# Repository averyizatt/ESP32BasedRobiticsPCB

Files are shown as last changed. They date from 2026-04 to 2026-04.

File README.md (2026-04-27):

# ESP32-S3 Robotics Controller PCB

<div align="center">







**A professional-grade, 4-layer ESP32-S3 robotics controller PCB that consolidates motor control, multi-axis sensing, and user interaction into a single, scalable platform.**

</div>

---

## Table of Contents

1. [Board Gallery](#board-gallery)
2. [System Architecture](#system-architecture)
3. [Feature Overview](#feature-overview)
4. [PCB Design](#pcb-design)
   - [Layer Stackup](#layer-stackup)
   - [Signal Integrity](#signal-integrity)
   - [Key Components (BOM Summary)](#key-components-bom-summary)
5. [GPIO Pin Reference](#gpio-pin-reference)
6. [Peripheral Details](#peripheral-details)
   - [Motor Control — DRV8871](#motor-control--drv8871)
   - [Servo Outputs](#servo-outputs)
   - [Ultrasonic Sensors — HC-SR04](#ultrasonic-sensors--hc-sr04)
   - [Hall Effect Sensors](#hall-effect-sensors)
   - [IMU — I2C](#imu--i2c)
   - [SPI Display](#spi-display)
   - [Push Buttons](#push-buttons)
   - [Expansion Header](#expansion-header)
7. [Firmware](#firmware)
   - [Quick Start](#quick-start)
   - [Library Dependencies](#library-dependencies)
   - [Firmware Architecture](#firmware-architecture)
   - [PWM Configuration](#pwm-configuration)
   - [WiFi Access Point & Web Dashboard](#wifi-access-point--web-dashboard)
   - [BLE GATT Server](#ble-gatt-server)
   - [On-Device UI](#on-device-ui)
     - [Main Menu](#main-menu)
     - [Robot Modes](#robot-modes)
     - [Games](#games)
8. [Repository Structure](#repository-structure)
9. [Hardware Files](#hardware-files)
10. [Contributing](#contributing)
11. [License](#license)

---

## Board Gallery

<div align="center">

| PCB Layout (Top) | 3D Render | PCB Back |
|:---:|:---:|:---:|
| PCB Layout | PCB 3D Render | PCB Back |

</div>

---

## System Architecture

The diagram below shows how all onboard subsystems connect to the ESP32-S3:

```
                        ┌─────────────────────────────────────┐
                        │           ESP32-S3-WROOM-1           │
                        │     240 MHz Xtensa LX7 Dual-Core     │
                        │     WiFi 802.11 b/g/n  •  BT 5.0    │
                        └───┬───┬───┬───┬───┬───┬───┬───┬─────┘
                            │   │   │   │   │   │   │   │
          ┌─────────────────┘   │   │   │   │   │   │   └──────────────────┐
          │ LEDC PWM            │   │   │   │   │   │ GPIO ISR             │
          ▼                     │   │   │   │   │   ▼                      │
 ┌─────────────────┐            │   │   │   │   │  ┌────────────────┐      │
 │   DRV8871 ×2    │            │   │   │   │   │  │  Hall Sensors  │      │
 │  DC Motor Ctrl  │            │   │   │   │   │  │   ×2 inputs    │      │
 │  (PWM IN1/IN2)  │            │   │   │   │   │  └────────────────┘      │
 └────────┬────────┘            │   │   │   │   │                          │
          │ VM (motor power)    │   │   │   │   │ INPUT_PULLUP             │
          ▼                     │   │   │   │   ▼                          │
    ┌───────────┐               │   │   │   │  ┌──────────────┐            │
    │  Motor ×2 │               │   │   │   │  │  Buttons ×2  │            │
    └───────────┘               │   │   │   │  └──────────────┘            │
                      PWM 50Hz  │   │   │   │                              │
                                ▼   │   │   │ SPI                          │
                       ┌────────────┐  │   ▼                               │
                       │  Servo 1   │  │  ┌──────────────────┐             │
                       └────────────┘  │  │   SPI Display    │             │
                                       │  │  (ST7735 etc.)   │             │
                    HC-SR04 TRIG/ECHO  │  └──────────────────┘             │
                                       ▼                                   │
                           ┌────────────────────┐                          │
                           │  Ultrasonic ×4     │                          │
                           │  (distance 2–400cm)│                          │
                           └────────────────────┘                          │
                                                                           │
          ┌────────────────────────────────────────────────────────────────┘
          │ I2C 400 kHz
          ▼
 ┌──────────────────┐     ┌──────────────────────────────┐
 │  IMU Header      │     │      Power Architecture       │
 │  MPU-6050 /      │     │  VM (7–12 V) ──► DRV8871     │
 │  ICM-42688 etc.  │     │  VM ──► 3.3 V LDO ──► ESP32  │
 └──────────────────┘     │  VM ──► 5 V (servo/sensors)  │
                          └──────────────────────────────┘
```

---

## Feature Overview

| Subsystem | Component | Capability |
|---|---|---|
| **Microcontroller** | ESP32-S3-WROOM-1 | 240 MHz dual-core, WiFi, BT 5.0, 45 GPIOs |
| **Motor Drivers** | 2× DRV8871 | H-bridge, 3.6 A peak, bidirectional DC control |
| **Servo Outputs** | 1 active channel | Servo 1 on GPIO 8; GPIO 9 is used by the menu potentiometer |
| **Ultrasonic Sensors** | 4× HC-SR04 | 2–400 cm range, 15° beam angle |
| **Hall Effect Sensors** | 2× inputs | Wheel speed, pulse counting, position feedback |
| **IMU** | I2C header | MPU-6050, ICM-42688, or any I2C IMU |
| **SPI Display** | ST7735S 160×80 | TFT_eSPI driver, tabbed on-device UI |
| **Push Buttons** | 2× SMD tactile | Top = enter/select, bottom = back/stop; debounced in firmware |
| **Expansion** | GPIO header | GPIO 40, 43, 44, and shared GPIO 48 available for expansion |
| **Power** | LDO + distribution | Onboard 3.3 V regulation, motor VM bus |
| **WiFi AP** | Soft Access Point | SSID `RoboController`, live sensor dashboard |
| **Web Dashboard** | AsyncWebSocket | Tabbed UI: sensors, WiFi scan, BLE radar, drive control |
| **Remote Control** | WebSocket JSON | Browser joystick → motor drive; Servo 1 slider |
| **BLE GATT Server** | NimBLE-Arduino | Sensor notify + motor/servo write characteristics |
| **BLE Scanner** | Passive scan | Detect nearby BLE devices, shown on TFT and dashboard |

---

## PCB Design

### Layer Stackup

The board uses a **4-layer stackup** (1.6 mm total thickness) to provide dedicated power and ground planes, minimizing noise and improving signal integrity:

```
  ┌─────────────────────────────────────────────┐  ← Component side
  │  Layer 1 — F.Cu (Top)                        │  Signal routing + high-current motor traces
  ├─────────────────────────────────────────────┤
  │  Prepreg                                     │
  ├─────────────────────────────────────────────┤
  │  Layer 2 — In1.Cu                            │  Solid GND plane (unbroken)
  ├─────────────────────────────────────────────┤
  │  Core                                        │
  ├─────────────────────────────────────────────┤
  │  Layer 3 — In2.Cu                            │  VM + 3.3 V power distribution
  ├─────────────────────────────────────────────┤
  │  Prepreg                                     │
  ├─────────────────────────────────────────────┤
  │  Layer 4 — B.Cu (Bottom)                     │  Additional signals + local copper pours
  └─────────────────────────────────────────────┘  ← Solder side
```

| Layer | Role | Trace Width |
|---|---|---|
| F.Cu (Top) | Signal routing + high-current motor paths | 0.2 mm signal / 2.0 mm motor VM |
| In1.Cu | Solid GND reference plane | — |
| In2.Cu | VM + 3.3 V power distribution | 0.8 mm+ |
| B.Cu (Bottom) | Additional signals + local copper pours | 0.2 mm signal |

### Signal Integrity

> **Design decisions to ensure reliable operation in a noisy motor-drive environment:**

- **Continuous GND plane** on In1.Cu with stitching vias throughout — minimises return-path inductance for both digital signals and motor switching transients.
- **Wide copper pours** on VM traces and high-current motor paths — rated for DRV8871 peak current with thermal headroom.
- **Local decoupling capacitors** placed directly at each ESP32-S3 power pin and each DRV8871 VCC/VM pin — suppresses switching noise at the source.
- **Physical separation** between sensitive I2C/SPI/UART traces and high-current motor/PWM traces — reduces capacitive and inductive coupling.
- **Short SPI routes** between ESP32-S3 and the display connector — maintains signal integrity at SPI bus speeds.
- **Motor VM routed on power layer (In2.Cu)** — keeps motor current off the signal layers.

### Key Components (BOM Summary)

| Reference | Part | Package | Description |
|---|---|---|---|
| U1 | ESP32-S3-WROOM-1 | SMD module | Main MCU — 240 MHz, WiFi, BT 5.0 |
| U2 | DRV8871 | HSOP-8 | Motor driver — Motor 1 |
| U3 | DRV8871 | HSOP-8 | Motor driver — Motor 2 |
| U4 | 3.3 V LDO | SOT-223 | 3.3 V regulated power for MCU and logic |
| J1–J4 | HC-SR04 headers | 4-pin 2.54 mm | Ultrasonic sensor connectors |
| J5–J6 | Hall sensor headers | 3-pin 2.54 mm | Hall effect sensor connectors |
| J7–J8 | Motor terminals | 2-pin screw terminal | Motor output connections |
| J9 | Expansion header | 8-pin 2.54 mm | Breakout for unused GPIO |
| J10 | Display header | 7-pin 2.54 mm | SPI display connector |
| SW1–SW2 | Tactile switches | SMD | User input buttons used by current firmware |

> Full BOM with part numbers and quantities is available in [`hardware/bom/`](hardware/bom/).

---

## GPIO Pin Reference

| GPIO | Function | Type | Notes |
|---|---|---|---|
| 1 | Hall Sensor 1 | Digital Input | Interrupt-driven pulse counting |
| 2 | Hall Sensor 2 | Digital Input | Interrupt-driven pulse counting |
| 4 | Motor 1 PWM A | LEDC Output | 20 kHz PWM, 8-bit resolution |
| 5 | Motor 1 PWM B | LEDC Output | 20 kHz PWM, 8-bit resolution |
| 6 | Motor 2 PWM A | LEDC Output | 20 kHz PWM, 8-bit resolution |
| 7 | Motor 2 PWM B | LEDC Output | 20 kHz PWM, 8-bit resolution |
| 8 | Servo 1 | PWM Output | 50 Hz via ESP32Servo library |
| 9 | Potentiometer | ADC Input | Main menu scroll / analog control; Servo 2 disabled in firmware |
| 10 | Ultrasonic 1 TRIG | Digital Output | 10 µs trigger pulse |
| 11 | Ultrasonic 1 ECHO | Digital Input | Pulse width → distance |
| 12 | Ultrasonic 2 TRIG | Digital Output | |
| 13 | Ultrasonic 2 ECHO | Digital Input | |
| 14 | Ultrasonic 3 TRIG | Digital Output | |
| 15 | Ultrasonic 3 ECHO | Digital Input | |
| 16 | Ultrasonic 4 TRIG | Digital Output | |
| 17 | Ultrasonic 4 ECHO | Digital Input | |
| 18 | I2C SDA (IMU) | I2C | 400 kHz fast mode |
| 21 | I2C SCL (IMU) | I2C | 400 kHz fast mode |
| 35 | SPI CS | SPI | Active low chip select |
| 36 | SPI DC | Digital Output | Data/Command select |
| 37 | SPI MOSI (Display) | SPI | SDA label on display module |
| 38 | SPI SCLK (Display) | SPI | SCL label on display module |
| 39 | SPI RES | Digital Output | Display reset |
| 41 | Button 1 | Digital Input | `INPUT_PULLUP`, active LOW |
| 42 | Button 2 | Digital Input | `INPUT_PULLUP`, active LOW |
| 48 | Onboard RGB LED | Digital Output | WS2812 / NeoPixel |
| 40, 43, 44 | Expansion Header | GPIO | General purpose — broken out to J9 |

---

## Peripheral Details

### Motor Control — DRV8871

The **DRV8871** is a brushed DC motor driver with an integrated H-bridge, supporting up to **3.6 A peak** current with current-limit protection. Two independent drivers are included for dual-motor operation.

| Motor | PWM A GPIO | PWM B GPIO | LEDC Channel A | LEDC Channel B |
|---|---|---|---|---|
| Motor 1 | 4 | 5 | 0 | 1 |
| Motor 2 | 6 | 7 | 2 | 3 |

**Control truth table:**

| Mode | PWM A | PWM B | Description |
|---|---|---|---|
| Forward | PWM duty | LOW | Speed proportional to duty cycle |
| Reverse | LOW | PWM duty | Speed proportional to duty cycle |
| Coast | LOW | LOW | Motor freewheels (no braking) |
| Brake | HIGH | HIGH | Active braking, motor stops quickly |

```cpp
// Example: drive Motor 1 forward at ~70% speed
motor_set(MotorId::MOTOR1, 180);   // 180/255 ≈ 70%

// Brake Motor 1
motor_brake(MotorId::MOTOR1);

// Coast Motor 2
motor_coast(MotorId::MOTOR2);
```

> **PWM frequency:** 20 kHz (above audible range — eliminates motor whine).  
> **Resolution:** 8-bit (0–255 duty cycle values).

---

### Servo Outputs

Servo 1 outputs a standard 50 Hz RC-servo PWM signal compatible with common hobby servos. Servo 2 hardware exists on GPIO 9, but the current firmware repurposes GPIO 9 as the ADC potentiometer input, so only Servo 1 is active.

| Servo | GPIO | Pulse Width Range |
|---|---|---|
| Servo 1 | 8 | 1000–2000 µs |
| Servo 2 | 9 | Disabled in current firmware; GPIO 9 is `POT_PIN` |

**Pulse width to angle mapping:**

```
1000 µs  ──►  0°   (full left)
1500 µs  ──►  90°  (center / neutral)
2000 µs  ──►  180° (full right)
```

```cpp
// Example: center Servo 1
servo_set_angle(ServoId::SERVO1, 90);
```

---

### Ultrasonic Sensors — HC-SR04

Four **HC-SR04** interfaces provide omnidirectional environmental awareness. Each sensor uses two GPIO pins: one for triggering and one for echo timing.

| Sensor | TRIG GPIO | ECHO GPIO | Max Range | Beam Angle |
|---|---|---|---|---|
| Sensor 1 | 10 | 11 | ~400 cm | ~15° |
| Sensor 2 | 12 | 13 | ~400 cm | ~15° |
| Sensor 3 | 14 | 15 | ~400 cm | ~15° |
| Sensor 4 | 16 | 17 | ~400 cm | ~15° |

**Operating principle:**

```
MCU                    HC-SR04
 │                        │
 │── 10 µs HIGH ─────────►│  TRIG pulse sent
 │                        │── 40 kHz ultrasonic burst ──►
 │                        │                    ◄── echo return
 │◄── pulse width (ECHO) ─│  width ∝ distance
 │
 Distance (cm) = pulse_width_µs × 0.0343 / 2
```

> **Timeout:** 30 ms (~5 m) — sensors beyond range return -1.

---

### Hall Effect Sensors

Two digital Hall effect sensor inputs support wheel speed measurement, odometry, and position feedback. Sensors are read via GPIO interrupts for accurate pulse counting.

| Sensor | GPIO | Mode |
|---|---|---|
| Hall 1 | 1 | Interrupt (rising edge) |
| Hall 2 | 2 | Interrupt (rising edge) |

```cpp
// Example: read rotational speed
float pps1 = hall_get_pulses_per_second(1);   // pulses per second
float pps2 = hall_get_pulses_per_second(2);
```

To calculate RPM, divide pulses per second by the number of magnet poles on the wheel.

---

### IMU — I2C

A dedicated I2C header supports any standard I2C IMU module.

| Signal | GPIO | Frequency |
|---|---|---|
| SDA | 18 | 400 kHz (fast mode) |
| SCL | 21 | 400 kHz (fast mode) |

**Compatible IMUs (non-exhaustive):**

| Part | Axes | Interface |
|---|---|---|
| MPU-6050 | 6-axis (accel + gyro) | I2C (0x68 / 0x69) |
| ICM-42688 | 6-axis (accel + gyro) | I2C / SPI |
| BNO055 | 9-axis (+ magnetometer, fusion) | I2C (0x28 / 0x29) |
| LSM6DSO | 6-axis | I2C / SPI |

```cpp
// Example: read IMU data
ImuData imu;
if (imu_read(imu)) {
    // accel in g, gyro in °/s
    Serial.printf("ax=%.2f  ay=%.2f  az=%.2f\n",
                  imu.accel_x, imu.accel_y, imu.accel_z);
}
```

---

### SPI Display

An SPI display connector supports ST7735, ST7789, ILI9341, or any SPI display with a compatible driver.

| Signal | GPIO | Function |
|---|---|---|
| MOSI (SDA) | 37 | Data to display |
| SCLK (SCL) | 38 | SPI clock |
| CS | 35 | Chip select (active LOW) |
| DC | 36 | Data / Command select |
| RES | 39 | Hardware reset |

The firmware uses **TFT_eSPI** for hardware-accelerated graphics and text rendering on the ST7735S 160×80 display. A custom colour palette and tabbed on-device UI are implemented in `display.h/cpp` and `ui.h/cpp`.

---

### Push Buttons

The current firmware uses two tactile buttons. Firmware enables `INPUT_PULLUP`, treats `LOW` as pressed, and applies software debouncing with `BUTTON_DEBOUNCE_MS` (default 20 ms).

| Button | GPIO | UI Role |
|---|---|---|
| Top button / Button 1 | 41 | Enter, open, select, primary action |
| Bottom button / Button 2 | 42 | Back, stop, return to menu |

GPIO 47 / Button 3 is not populated or used by the current 2-button UI.

```cpp
// Example: detect button press events
buttons_update();   // call every loop iteration

if (nav_enter_just_pressed()) {
    // top button pressed
}

if (nav_back_just_pressed()) {
    // bottom button pressed
}
```

---

### Expansion Header

Several GPIO pins are broken out on **J9** for custom peripherals, additional sensors, or future expansion. Some physical header pins are shared with active firmware functions, so check `config.h` before reusing them.

| Header Pin | GPIO | Notes |
|---|---|---|
| 1 | 37 | SPI display MOSI in current firmware |
| 2 | 38 | SPI display SCLK in current firmware |
| 3 | 40 | General purpose |
| 4 | 43 | UART0 TX (also used for USB CDC) |
| 5 | 44 | UART0 RX (also used for USB CDC) |
| 6 | 48 | Onboard RGB LED / WS2812 |
| 7 | 3.3 V | Power rail |
| 8 | GND | Ground |

> GPIO 43 and 44 are the default UART0 pins and can be used for serial communication with external devices.

---

## Firmware

### Quick Start

```bash
# 1. Clone the repository
git clone https://github.com/averyizatt/ESP32BasedRobiticsPCB.git

# 2. Open in PlatformIO (recommended)
#    File → Open Folder → ESP32BasedRobiticsPCB
#    PlatformIO auto-resolves all lib_deps from platformio.ini

# 3. Build
pio run --environment esp32s3

# 4. Upload
pio run --target upload --environment esp32s3
```

1. Install **PlatformIO** (VS Code extension or CLI)
2. Open the repo root as the workspace
3. PlatformIO resolves all library dependencies automatically from `platformio.ini`
4. Select the **esp32s3** environment, build, and upload
5. After boot, connect to WiFi SSID `RoboController` (password `robot1234`) and navigate to `http://192.168.4.1`

### Library Dependencies

All dependencies are declared in `platformio.ini` and resolved automatically by PlatformIO. For manual Arduino IDE installs use the Library Manager names below.

| Library | Version | Purpose |
|---|---|---|
| `madhephaestus/ESP32Servo` | ^3.0.6 | RC servo 50 Hz PWM |
| `bodmer/TFT_eSPI` | ^2.5.43 | ST7735S SPI display driver + graphics |
| `ESP32Async/AsyncTCP` | ^3.3.2 | Async TCP foundation for web server |
| `ESP32Async/ESPAsyncWebServer` | ^3.7.4 | Async HTTP + WebSocket server |
| `h2zero/NimBLE-Arduino` | ^1.4.3 | BLE stack (GATT server + scanning) |
| `Wire` | built-in | I2C for IMU |
| `WiFi` | built-in | Soft AP + network scanning |

> **TFT_eSPI user config:** The library reads pin assignments from `User_Setup.h`. Ensure the file in your PlatformIO build includes the ST7735S settings matching `config.h` (MOSI=37, SCLK=38, CS=35, DC=36, RST=39).

### Firmware Architecture

The firmware is organized as a set of independent peripheral modules — each with its own header and source file — all coordinated from `main.cpp`:

```
ESP32RoboticsController/
├── main.cpp                         ← setup() + loop() entry point
├── config.h                         ← All pin definitions and tuning constants
│
├── motors.h / motors.cpp            ← DRV8871 LEDC-based motor control
├── servos.h / servos.cpp            ← RC servo PWM control
├── ultrasonics.h / ultrasonics.cpp  ← HC-SR04 distance measurement
├── hall_sensors.h / hall_sensors.cpp← Interrupt-based pulse counting
├── imu.h / imu.cpp                  ← I2C IMU read abstraction (MPU-6050)
├── buttons.h / buttons.cpp          ← Debounced button state machine
├── led.h / led.cpp                  ← Onboard LED control
├── pot.h / pot.cpp                  ← Potentiometer / ADC helper
│
├── display.h / display.cpp          ← TFT_eSPI display abstraction + colour palette
├── ui.h / ui.cpp                    ← On-device tabbed UI state machine
├── games.h / games.cpp              ← Mini-game / demo logic
├── autonomous_modes.h / autonomous_modes.cpp
│                                      ← Autonomous driving state machine
├── robot_modes.h / robot_modes.cpp  ← Robot mode selector + active-mode runner
│
└── wifi_server.h / wifi_server.cpp  ← WiFi soft AP, AsyncWebServer, WebSocket push,
                                        BLE GATT server, WiFi/BLE scanner helpers
```

All pin assignments and tunable parameters are centralized in `config.h` — adapting the firmware to a modified hardware revision only requires editing that single file.

### PWM Configuration

Motor PWM is generated using the ESP32-S3's **LEDC peripheral**, which provides hardware-timed PWM independent of the CPU:

| Parameter | Value | Notes |
|---|---|---|
| Frequency | 20 kHz | Above human hearing — eliminates audible motor whine |
| Resolution | 8-bit | 0–255 duty cycle values |
| Channels | 4 (0–3) | One per motor H-bridge input |

---

### WiFi Access Point & Web Dashboard

The firmware starts a **soft Access Point** on boot. Connect any browser-capable device to control and monitor the robot.

| Setting | Value |
|---|---|
| SSID | `RoboController` |
| Password | `robot1234` |
| IP Address | `192.168.4.1` |
| WebSocket | `ws://192.168.4.1/ws` |

The dashboard is a single-page app served from PROGMEM with four tabs:

| Tab | Contents |
|---|---|
| **Sensors** | Live IMU (accel + gyro axis bars), ultrasonic proximity radar, heap gauge, hall encoder counts, button tiles, uptime |
| **WiFi Scanner** | Scan nearby networks — SSID, signal strength bar, channel, security badge |
| **BLE Radar** | Scan for BLE devices — name, RSSI, MAC address |
| **Control** | Virtual joystick (touch + mouse), Servo 1 control, emergency stop, command log |

Sensor data is pushed over **WebSocket** (no polling) at a configurable interval (`WIFI_WS_PUSH_MS`, default 200 ms).

#### REST Endpoints

| Endpoint | Method | Response |
|---|---|---|
| `/` | GET | Full HTML dashboard |
| `/api/scan` | GET | JSON array of nearby WiFi networks |
| `/api/ble` | GET | JSON array of scanned BLE devices (~4 s scan) |

#### WebSocket Commands (browser → robot)

The robot accepts inbound JSON commands over the same WebSocket connection:

```json
// Drive both motors (speed: -255 to +255)
{ "t": "drive", "l": 200, "r": -150 }

// Set Servo 1 angle (angle: 0–180°)
{ "t": "servo", "id": 1, "angle": 90 }

// Emergency stop — coasts both motors
{ "t": "stop" }
```

---

### BLE GATT Server

The firmware advertises a custom BLE GATT service alongside the WiFi AP — connect from **nRF Connect**, **LightBlue**, or any GATT-capable app.

| Item | UUID | Properties | Format |
|---|---|---|---|
| Service | `AB12` | — | — |
| Sensor Notify | `AA13` | Read + Notify | Compact JSON: accel, gyro, ultrasonic |
| Motor Write | `AA14` | Write | `l:<speed>,r:<speed>` e.g. `l:200,r:-150` |
| Servo Write | `AA15` | Write | `<id>:<angle>` e.g. `1:90` |

The sensor characteristic sends a live data notification every **500 ms** when a central is connected:

```json
{"ax":0.01,"ay":-0.03,"az":9.81,"gx":0.2,"gy":-0.1,"gz":0.0,"u":[45.2,120.0,-1.0,88.4]}
```

(`u` values are ultrasonic distances in cm; `-1` = no echo / out of range)

---

### On-Device UI

A tabbed menu system runs on the 160×80 TFT display. Navigation uses two push buttons and the onboard potentiometer. An auto-idle screensaver activates after 20 seconds of inactivity.

**Navigation:**
- **Top button / GPIO 41** — enter, open, select, or primary action
- **Bottom button / GPIO 42** — back, stop active mode, or return to menu
- **Potentiometer** — main menu selection and analog controls inside demos/games

In the main menu the potentiometer maps directly across the list: pot minimum selects the first item, and pot maximum selects the last item. It does not wrap around.

#### Main Menu

| Menu Item | Screen | Description |
|---|---|---|
| Sensors | Live readout | All sensor values: ultrasonic distances, hall encoder counts, button states, uptime |
| IMU Data | Live readout | Accelerometer (X/Y/Z in g) and gyroscope (X/Y/Z in °/s) with temperature |
| Tilt Demo | Animation | Graphical liquid-level tilt visualiser driven by IMU pitch/roll |
| Motors | Live readout | Current motor speed and direction for both motor channels |
| Ultrasonic | Radar demo | Real-time 4-direction proximity radar on TFT |
| Hall Demo | Live readout | Wheel pulse counts and pulses-per-second for both encoder channels |
| Servo Demo | Manual servo control | Servo 1 starts at 90°; moving the pot commands 0–180° |
| System | Info screen | Firmware uptime, heap usage, CPU frequency, chip info |
| Games | Sub-menu | Arcade game launcher (see Games section below) |
| Robot Modes | Sub-menu | Autonomous / RC mode launcher; bottom button stops active mode |
| WiFi Info | Info screen | AP SSID, password, IP address, connected client count |
| WiFi Scan | Scanner | Nearby WiFi networks with RSSI bars; pot scrolls list |
| BLE Radar | Scanner | Nearby BLE devices with RSSI bars; 4-second active scan |

#### Robot Modes

The Robot Modes menu starts the autonomous-mode engine from the display UI. The top button starts the highlighted mode, the bottom button exits the menu, and while a mode is running the bottom button stops the mode and returns to the Robot Modes list.

| Mode | Description |
|---|---|
| RC Control | Xbox BLE joystick / tank-drive control |
| UART Control | UART-commanded forward control |
| Socket Ctrl | Socket motor pass-through |
| Autonomous | Advanced state-machine mode |
| Simple Auto | PID forward motion with recovery behavior |
| Wall Follow | Left-hand PID wall follower |
| Premap Nav | Map-seeded autonomous navigation |

#### Games

The Games menu launches a sub-menu with three sprite-rendered arcade games. All games use a **full-screen off-screen framebuffer** (TFT_eSprite) pushed via DMA for zero-flicker 40 fps rendering. Win/loss statistics are stored in RAM for the session and displayed in the game menu next to each title.

---

##### Snake

> Classic snake — eat food to grow, avoid your own tail. Walls wrap.

| Detail | Value |
|---|---|
| Grid | 40 × 14 cells (4 px each) |
| Win condition | Score 20 food pieces |
| Controls | Potentiometer zones or top button to turn; bottom returns from game-over/menu screens |
| Speed | Increases with score (160 ms → 50 ms minimum tick) |
| Visual effects | Gradient tail fade, pulsing food, particle burst on eat/death, screen shake on collision |

---

##### Pong

> Single-player Pong — keep the ball alive and score paddle hits.

| Detail | Value |
|---|---|
| Win condition | 10 paddle hits |
| Lives | 3 |
| Controls | Potentiometer maps directly to paddle Y position; top button retries from game-over |
| Difficulty | Ball speed +0.15 per hit, capped at 5.5 px/frame |
| Visual effects | 6-frame ball trail, glowing neon paddle, particle bursts on wall/paddle hits, screen shake on miss |

---

##### Asteroids

> Side-scrolling asteroid dodge — survive as long as possible.

| Detail | Value |
|---|---|
| Win condition | Survive 1500 score ticks (~37 s at 40 fps) |
| Lives | 3 |
| Controls | Potentiometer steers ship Y (smoothed); top button retries from game-over |
| Difficulty | Rock speed 2.2 → 5.0 px/frame; spawn interval 1100 → 350 ms |
| Visual effects | 3-layer parallax starfield, procedural 8-vertex asteroid shapes, thruster flame + exhaust particles, invulnerability blink after hit, screen shake on collision |

---

All three games share:
- **Particle system** — 24-particle pool with gravity and colour fade, reused across all effects
- **Screen shake** — configurable intensity applied as DMA push offset
- **Session W/L stats** — shown in the games menu and on the game-over screen
- **LED feedback** — green on score/win, red on death/hit, blue on game start

---

## Repository Structure

```
ESP32BasedRobiticsPCB/
│
├── platformio.ini                     ← PlatformIO project config + lib_deps
│
├── firmware/
│   └── ESP32RoboticsController/
│       ├── main.cpp                   ← setup() + loop() entry point
│       ├── config.h                   ← Pin map & constants (start here)
│       ├── motors.h / motors.cpp      ← DRV8871 LEDC motor control
│       ├── servos.h / servos.cpp      ← RC servo PWM
│       ├── ultrasonics.h / ultrasonics.cpp  ← HC-SR04 distance
│       ├── hall_sensors.h / hall_sensors.cpp← Interrupt pulse counting
│       ├── imu.h / imu.cpp            ← MPU-6050 I2C abstraction
│       ├── buttons.h / buttons.cpp    ← Debounced buttons
│       ├── led.h / led.cpp            ← Onboard LED
│       ├── pot.h / pot.cpp            ← ADC potentiometer
│       ├── display.h / display.cpp    ← TFT_eSPI wrapper + colour palette
│       ├── ui.h / ui.cpp              ← On-device tabbed UI state machine
│       ├── games.h / games.cpp        ← Demo / mini-game logic
│       ├── autonomous_modes.h / autonomous_modes.cpp
│       │                                ← Autonomous driving state machine
│       ├── robot_modes.h / robot_modes.cpp
│       │                                ← Robot mode selector + active-mode runner
│       └── wifi_server.h / wifi_server.cpp  ← WiFi AP, web dashboard,
│                                              WebSocket, BLE GATT
│
└── hardware/                          # KiCad 7 PCB design files
    ├── kicadProject/
    │   ├── Tank.kicad_pro
    │   ├── Tank.kicad_sch
    │   ├── Tank.kicad_pcb
    │   └── Tank.step
    ├── gerbers/                        ← Fabrication-ready Gerber files
    └── bom/                            ← Bill of materials (bom.csv)
```

---

## Hardware Files

KiCad design files are in the [`hardware/`](hardware/) directory.

1. Install [KiCad 7](https://www.kicad.org/download/) or later
2. Open `hardware/kicadProject/Tank.kicad_pro`
3. The schematic opens in **Eeschema**; the PCB layout opens in **Pcbnew**

**Generating Gerbers for fabrication** (Pcbnew → File → Fabrication Outputs → Gerbers):

| File | Layer |
|---|---|
| `*-F_Cu.gbr` | Top copper |
| `*-In1_Cu.gbr` | Inner GND plane |
| `*-In2_Cu.gbr` | Inner power plane |
| `*-B_Cu.gbr` | Bottom copper |
| `*-F_SilkS.gbr` / `*-B_SilkS.gbr` | Silkscreen |
| `*-F_Mask.gbr` / `*-B_Mask.gbr` | Solder mask |
| `*-F_Paste.gbr` | Solder paste |
| `*-Edge_Cuts.gbr` | Board outline |
| `*.drl` | Drill file (Excellon) |

Pre-generated Gerber files are available in [`hardware/gerbers/`](hardware/gerbers/).

---

## Contributing

Contributions are welcome! To contribute:

1. Fork the repository
2. Create a feature branch (`git checkout -b feature/my-improvement`)
3. Commit your changes with a clear message
4. Open a pull request describing what you changed and why

**For hardware changes:** please include updated Gerber files and a brief description of the PCB modification.  
**For firmware changes:** please test on hardware before submitting.

---

## License

MIT License — see [LICENSE](LICENSE) for details.

---

<div align="center">

Made with ❤️ for the robotics community

</div>

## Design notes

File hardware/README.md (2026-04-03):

# Hardware — KiCad PCB Design Files

This directory contains the KiCad 7 project for the ESP32-S3 Robotics Controller PCB.

## Files

| File | Description |
|---|---|
| `ESP32RoboticsController.kicad_pro` | KiCad project file |
| `ESP32RoboticsController.kicad_sch` | Schematic |
| `ESP32RoboticsController.kicad_pcb` | PCB layout |
| `ESP32RoboticsController.kicad_dru` | Design rules |
| `fp-lib-table` | Footprint library table |
| `sym-lib-table` | Symbol library table |
| `gerbers/` | Fabrication-ready Gerber files |
| `bom/` | Bill of materials |
| `datasheets/` | Component datasheets |

## PCB Stackup

| Layer | Role |
|---|---|
| F.Cu (Top) | Signal routing + high-current paths |
| In1.Cu | Solid GND plane |
| In2.Cu | VM + regulated power distribution |
| B.Cu (Bottom) | Additional signals + local pours |

## Key Components

| Reference | Part | Package |
|---|---|---|
| U1 | ESP32-S3-WROOM-1 | SMD module |
| U2 | DRV8871 (Motor 1) | HSOP-8 |
| U3 | DRV8871 (Motor 2) | HSOP-8 |
| U4 | 3.3 V LDO regulator | SOT-223 |
| J1–J4 | Ultrasonic sensor headers | 4-pin 2.54 mm |
| J5–J6 | Hall sensor headers | 3-pin 2.54 mm |
| J7–J8 | Motor terminals | 2-pin screw terminal |
| J9 | Expansion GPIO header | 8-pin 2.54 mm |
| J10 | SPI display header | 7-pin 2.54 mm |
| SW1–SW3 | Push buttons | SMD tactile |
| DSP1 | SPI display (e.g., ST7735) | connector |

## Opening the Project

1. Install [KiCad 7](https://www.kicad.org/download/)
2. Open `ESP32RoboticsController.kicad_pro`
3. The schematic opens in Eeschema; the PCB opens in Pcbnew

## Generating Gerbers

In Pcbnew: **File → Fabrication Outputs → Gerbers**

Recommended layers for 4-layer fabrication:
- F.Cu, In1.Cu, In2.Cu, B.Cu
- F.SilkS, B.SilkS
- F.Mask, B.Mask
- Edge.Cuts
- F.Paste

## Design Rules

- Min trace width: 0.2 mm (signal), 0.8 mm (power), 2.0 mm (motor VM)
- Min via drill: 0.3 mm
- Min clearance: 0.2 mm
- Board thickness: 1.6 mm

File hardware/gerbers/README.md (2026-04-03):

# Gerber Files

Place fabrication-ready Gerber files in this directory after generating them from KiCad.

## Required Files for 4-Layer PCB Fabrication

| File | Layer |
|---|---|
| `ESP32RoboticsController-F_Cu.gbr` | Top copper |
| `ESP32RoboticsController-In1_Cu.gbr` | Inner layer 1 (GND plane) |
| `ESP32RoboticsController-In2_Cu.gbr` | Inner layer 2 (Power) |
| `ESP32RoboticsController-B_Cu.gbr` | Bottom copper |
| `ESP32RoboticsController-F_SilkS.gbr` | Front silkscreen |
| `ESP32RoboticsController-B_SilkS.gbr` | Back silkscreen |
| `ESP32RoboticsController-F_Mask.gbr` | Front solder mask |
| `ESP32RoboticsController-B_Mask.gbr` | Back solder mask |
| `ESP32RoboticsController-F_Paste.gbr` | Front solder paste |
| `ESP32RoboticsController-Edge_Cuts.gbr` | Board outline |
| `ESP32RoboticsController.drl` | Drill file (excellon) |

## Generating from KiCad 7

1. Open PCB in Pcbnew
2. File → Fabrication Outputs → Gerbers
3. Select output directory: `hardware/gerbers/`
4. Enable all required layers above
5. Click "Plot", then "Generate Drill Files"

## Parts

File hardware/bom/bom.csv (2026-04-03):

Reference | Qty | Value | Footprint | Description
U1 | 1 | ESP32-S3-WROOM-1 | RF_Module:ESP32-S3-WROOM-1 | ESP32-S3 WiFi+BT module
U2 | 1 | DRV8871 | Package_SO:HSOP-8_3.9x4.9mm_P1.27mm | H-bridge motor driver (Motor 1)
U3 | 1 | DRV8871 | Package_SO:HSOP-8_3.9x4.9mm_P1.27mm | H-bridge motor driver (Motor 2)
U4 | 1 | AMS1117-3.3 | Package_TO_SOT_SMD:SOT-223-3_TabPin2 | 3.3V 1A LDO regulator
C1 | 1 | 100uF | CP_EIA-3528-12_AVX-H | Bulk decoupling — input power
C2 | 1 | 10uF | C_0805_2012Metric | Bulk decoupling — 3.3V rail
C3-C10 | 8 | 100nF | C_0402_1005Metric | Decoupling — ESP32-S3 VDD pins
C11-C12 | 2 | 10uF | C_0805_2012Metric | Decoupling — DRV8871 VM
C13-C14 | 2 | 100nF | C_0402_1005Metric | Decoupling — DRV8871 VCC
C15-C16 | 2 | 100nF | C_0402_1005Metric | Decoupling — DRV8871 VM HF
R1-R2 | 2 | 10k | R_0402_1005Metric | I2C SDA/SCL pull-up
R3-R5 | 3 | 10k | R_0402_1005Metric | Button pull-up (if not using internal)
J1-J4 | 4 | Conn_01x04 | Connector_PinHeader_2.54mm:PinHeader_1x04_P2.54mm_Vertical | Ultrasonic sensor header (VCC GND TRIG ECHO)
J5-J6 | 2 | Conn_01x03 | Connector_PinHeader_2.54mm:PinHeader_1x03_P2.54mm_Vertical | Hall sensor header (VCC GND SIG)
J7-J8 | 2 | Conn_01x02 | Connector_Screw_PitchMetric:ScrewTerminal_1x02_P5.0mm | Motor terminal
J9 | 1 | Conn_01x08 | Connector_PinHeader_2.54mm:PinHeader_1x08_P2.54mm_Vertical | Expansion GPIO header
J10 | 1 | Conn_01x07 | Connector_PinHeader_2.54mm:PinHeader_1x07_P2.54mm_Vertical | SPI display header
J11 | 1 | Conn_01x02 | Connector_Screw_PitchMetric:ScrewTerminal_1x02_P5.0mm | Power input (VM)
J12 | 1 | Conn_01x04 | Connector_PinHeader_2.54mm:PinHeader_1x04_P2.54mm_Vertical | I2C IMU header
SW1-SW3 | 3 | SW_Push | Button_SMD:SW_SPST_TL3342 | Tactile push button

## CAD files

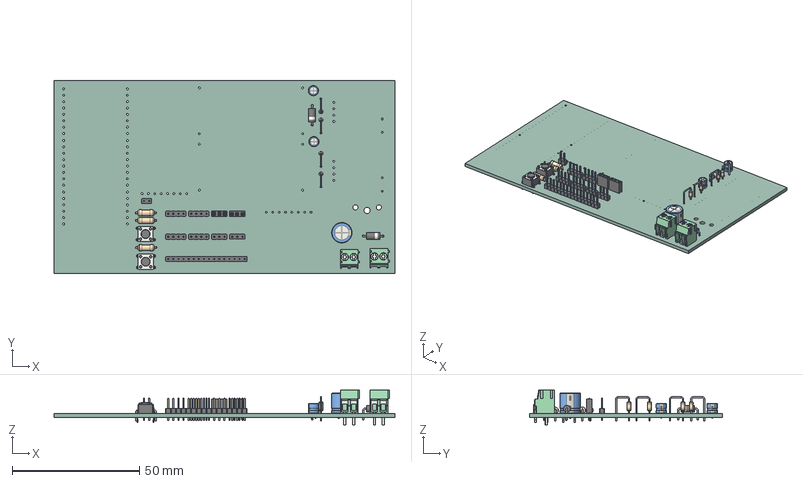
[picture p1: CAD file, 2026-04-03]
hardware/kicadProject/Tank.step
133.8 x 75.6 x 13.7 mm
PinHeader_1x04_P200mm_Vertical x 4
R_Axial_DIN0204_L36mm_D16mm_P508mm_Vertical x 4
CP_Radial_D80mm_P250mm
PinSocket_1x03_P200mm_Vertical x 2
SW_PUSH_6mm x 2
CP_Radial_D40mm_P150mm x 2
R_Axial_DIN0207_L63mm_D25mm_P762mm_Horizontal x 3
PinHeader_1x03_P200mm_Vertical x 2
TerminalBlock_Phoenix_PT_15_2_35_H_1x02_P350mm_Horizontal x 2
D_A-405_P7.62mm_Horizontal x 2
PinHeader_1x16_P200mm_Vertical
PinHeader_1x02_P200mm_Vertical
_autosave-Tank_PCB

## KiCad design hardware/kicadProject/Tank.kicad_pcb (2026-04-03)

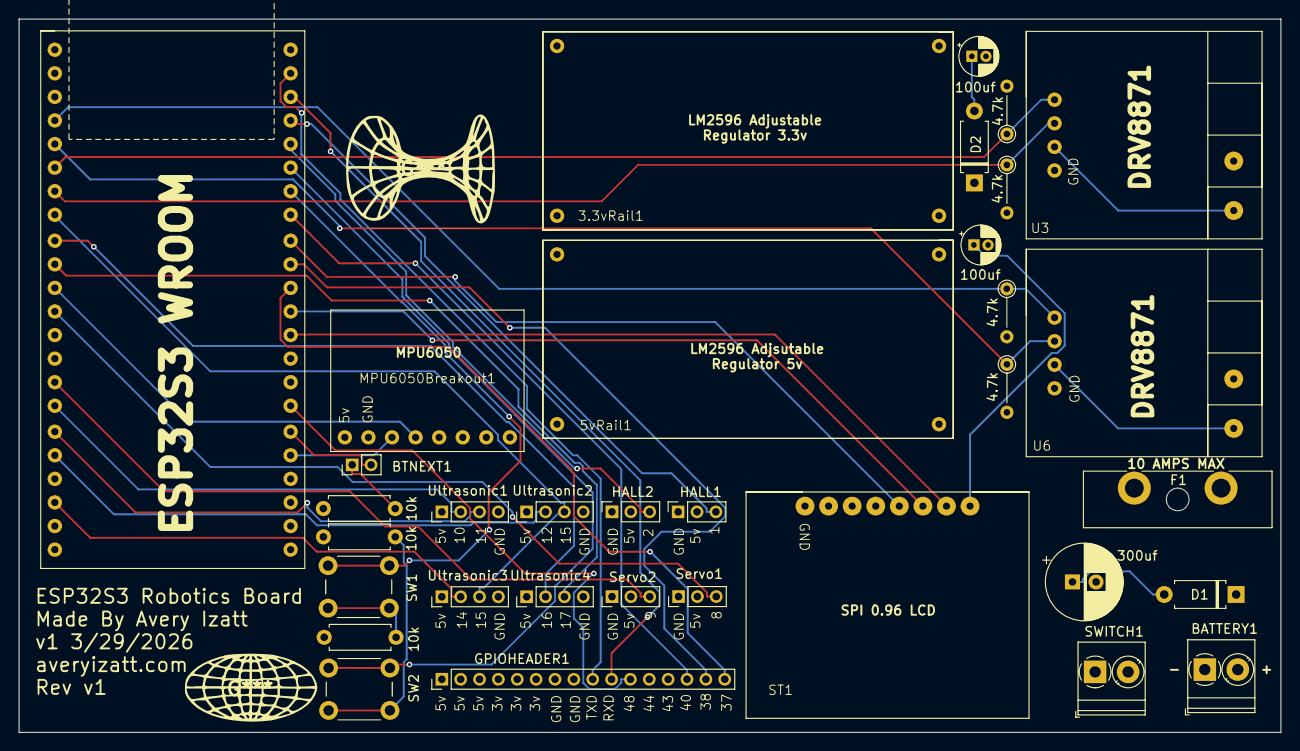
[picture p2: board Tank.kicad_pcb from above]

Board: 4 copper layers, 133.8 x 75.6 mm, 34 parts (0 on the bottom side), 40 nets.

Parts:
3.3vRail1, 5vRail1: LM2596Adj
4.7k, 4.7k#2, 4.7k#3, 4.7k#4: R; R_Axial_DIN0204_L3.6mm_D1.6mm_P5.08mm_Vertical
10k, 10k#2, 10k#3: R; R_Axial_DIN0207_L6.3mm_D2.5mm_P7.62mm_Horizontal
100uf, 100uf#2: C_Polarized; CP_Radial_D4.0mm_P1.50mm
300uf: C_Polarized; CP_Radial_D8.0mm_P2.50mm
BATTERY1: Screw_Terminal_2_P3.50mm; TerminalBlock_Phoenix_PT-1,5-2-3.5-H_1x02_P3.50mm_Horizontal
BTNEXT1: Conn_01x02_Pin; PinHeader_1x02_P2.00mm_Vertical
D1, D2: D; D_A-405_P7.62mm_Horizontal
ESP32-S3WROOM45Pin1: ESP32S3
F1: Fuse; Fuseholder_Blade_ATO_Littelfuse_Pudenz_2_Pin
GPIOHEADER1: Conn_01x16_Pin; PinHeader_1x16_P2.00mm_Vertical
HALL1, HALL2: Conn_01x03_Pin; PinSocket_1x03_P2.00mm_Vertical
MPU6050Breakout1: MPU6050
ST1: SPI 0.96 LCD
SW1, SW2: Push_Button; SW_PUSH_6mm
SWITCH1: Screw_Terminal_2_P3.50mm; TerminalBlock_Phoenix_PT-1,5-2-3.5-H_1x02_P3.50mm_Horizontal
Servo1, Servo2: Conn_01x03_Pin; PinHeader_1x03_P2.00mm_Vertical
U3, U6: DRV8871
Ultrasonic1, Ultrasonic2, Ultrasonic3, Ultrasonic4: Conn_01x04_Pin; PinHeader_1x04_P2.00mm_Vertical

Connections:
3.3V: 3.3vRail1.3 (OUT+), 100uf.1, ESP32-S3WROOM45Pin1.1 (3.3v), ESP32-S3WROOM45Pin1.2 (3.3v), GPIOHEADER1.4, GPIOHEADER1.5, GPIOHEADER1.6, ST1.2 (VCC), ST1.8 (BLK)
5V: 5vRail1.3 (OUT+), 100uf#2.1, D2.2 (A), GPIOHEADER1.1, GPIOHEADER1.2, GPIOHEADER1.3, HALL1.2, HALL2.2, MPU6050Breakout1.1 (VCC), Servo1.2, Servo2.2, Ultrasonic1.1, Ultrasonic2.1, Ultrasonic3.1, Ultrasonic4.1
GND: 3.3vRail1.2 (IN-), 3.3vRail1.4 (OUT-), 4.7k.2, 4.7k#2.2, 4.7k#3.2, 4.7k#4.2, 5vRail1.2 (IN-), 5vRail1.4 (OUT-), 10k.2, 10k#2.2, 10k#3.2, 100uf.2, 100uf#2.2, 300uf.2, BATTERY1.1, ESP32-S3WROOM45Pin1.22 (GND), ESP32-S3WROOM45Pin1.23 (GND), ESP32-S3WROOM45Pin1.43 (GND), ESP32-S3WROOM45Pin1.44 (GND), GPIOHEADER1.7, GPIOHEADER1.8, HALL1.1, HALL2.1, MPU6050Breakout1.2 (GND), ST1.1 (GND), Servo1.1, Servo2.1, U3.2 (GND), U3.6 (GND), U6.2 (GND), U6.6 (GND), Ultrasonic1.4, Ultrasonic2.4, Ultrasonic3.4, Ultrasonic4.4
GPIO1: ESP32-S3WROOM45Pin1.26 (GPIO1), HALL1.3
GPIO2: ESP32-S3WROOM45Pin1.27 (GPIO2), HALL2.3
GPIO4: 4.7k#4.1, ESP32-S3WROOM45Pin1.4 (GPIO4), U6.3 (IN1)
GPIO5: 4.7k#2.1, ESP32-S3WROOM45Pin1.5 (GPIO5), U6.4 (IN2)
GPIO6: 4.7k.1, ESP32-S3WROOM45Pin1.6 (GPIO6), U3.3 (IN1)
GPIO7: 4.7k#3.1, ESP32-S3WROOM45Pin1.7 (GPIO7), U3.4 (IN2)
GPIO8: ESP32-S3WROOM45Pin1.12 (GPIO8), Servo1.3
GPIO9: ESP32-S3WROOM45Pin1.15 (GPIO9), Servo2.3
GPIO10: ESP32-S3WROOM45Pin1.16 (GPIO10), Ultrasonic1.2
GPIO11: ESP32-S3WROOM45Pin1.17 (GPIO11), Ultrasonic1.3
GPIO12: ESP32-S3WROOM45Pin1.18 (GPIO12), Ultrasonic2.2
GPIO14: ESP32-S3WROOM45Pin1.20 (GPIO14), Ultrasonic3.2
GPIO15: ESP32-S3WROOM45Pin1.8 (GPIO15), Ultrasonic2.3, Ultrasonic3.3
GPIO16: ESP32-S3WROOM45Pin1.9 (GPIO16), Ultrasonic4.2
GPIO17: ESP32-S3WROOM45Pin1.10 (GPIO17), Ultrasonic4.3
GPIO18: ESP32-S3WROOM45Pin1.11 (GPIO18), MPU6050Breakout1.4 (SDA)
GPIO21: ESP32-S3WROOM45Pin1.40 (GPIO21), MPU6050Breakout1.3 (SCL)
GPIO35: ESP32-S3WROOM45Pin1.35 (GPIO35), ST1.7 (CS)
GPIO36: ESP32-S3WROOM45Pin1.34 (GPIO36), ST1.6 (DC)
GPIO37: ESP32-S3WROOM45Pin1.33 (GPIO37), GPIOHEADER1.16
GPIO38: ESP32-S3WROOM45Pin1.32 (GPIO38), GPIOHEADER1.15
GPIO39: ESP32-S3WROOM45Pin1.31 (GPIO39), ST1.5 (RES)
GPIO40: ESP32-S3WROOM45Pin1.30 (GPIO40), GPIOHEADER1.14
GPIO41: ESP32-S3WROOM45Pin1.29 (GPIO41), SW1.1
GPIO42: ESP32-S3WROOM45Pin1.28 (GPIO42), SW2.1
GPIO47: BTNEXT1.2, ESP32-S3WROOM45Pin1.39 (GPIO47)
GPIO48: ESP32-S3WROOM45Pin1.38 (GPIO48), GPIOHEADER1.11
unnamed: 3.3vRail1.1 (IN+), D2.1 (K)
unnamed: BATTERY1.2, F1.1
unnamed: 10k.1, BTNEXT1.1
unnamed: 300uf.1, D1.2 (A), SWITCH1.2
unnamed: F1.2, SWITCH1.1
unnamed: 10k#2.1, SW1.2
unnamed: 10k#3.1, SW2.2
RXD: ESP32-S3WROOM45Pin1.25 (RXD), GPIOHEADER1.10
TXD: ESP32-S3WROOM45Pin1.24 (TXD), GPIOHEADER1.9
VM: 5vRail1.1 (IN+), D1.1 (K), U3.1 (VM), U3.5 (VM), U6.1 (VM), U6.5 (VM)

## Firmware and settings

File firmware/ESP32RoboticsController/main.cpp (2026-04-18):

// =============================================================================
// ESP32-S3 Robotics Controller — Main Entry Point
// =============================================================================

#include <Arduino.h>
#include "config.h"
#include "display.h"
#include "buttons.h"
#include "motors.h"
#include "servos.h"
#include "ultrasonics.h"
#include "hall_sensors.h"
#include "imu.h"
#include "led.h"
#include "pot.h"
#include "wifi_server.h"
#include "ui.h"

void setup() {
    Serial.begin(115200);
    delay(200);
    Serial.println("\n[main] ESP32-S3 Robotics Controller");

    led_init();
    led_blue();

    Serial.println("[main] Initializing IMU on I2C...");
    bool imu_found = imu_init();
    Serial.printf("[main] IMU %s\n", imu_found ? "found" : "not found");

    // Display now uses its own SPI pins, so the IMU stays available on I2C.
    display_init();
    pot_init();

    wifi_server_init();

    // Boot sequence — shows splash, self-test, menu
    ui_boot(imu_found);
}

void loop() {
    buttons_update();
    pot_update();
    ui_update();
    wifi_server_update();
}

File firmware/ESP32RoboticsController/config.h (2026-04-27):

#pragma once

// =============================================================================
// ESP32-S3 Robotics Controller — Pin Configuration
// =============================================================================
// Board: ESP32S3 Dev Module
// Required libraries:
//   - ESP32Servo       (servo control)
//   - Wire             (I2C — built-in)
//   - SPI              (SPI — built-in)
//   - TFT_eSPI         (display driver, replaces Adafruit_ST7735)
//   - NimBLE-Arduino   (BLE GATT + scanner)
//   - ESPAsyncWebServer + AsyncTCP  (web dashboard)
// =============================================================================

// --- Motor 1 (DRV8871) ---
#define MOTOR1_PWM_A  4
#define MOTOR1_PWM_B  5

// --- Motor 2 (DRV8871) ---
#define MOTOR2_PWM_A  6
#define MOTOR2_PWM_B  7

// --- Servo Outputs ---
#define SERVO1_PIN    8
#define SERVO2_PIN    9

// --- Ultrasonic Sensors (HC-SR04) ---
#define ULTRASONIC1_TRIG  10
#define ULTRASONIC1_ECHO  11
#define ULTRASONIC2_TRIG  12
#define ULTRASONIC2_ECHO  13
#define ULTRASONIC3_TRIG  14
#define ULTRASONIC3_ECHO  15
#define ULTRASONIC4_TRIG  16
#define ULTRASONIC4_ECHO  17

// --- I2C (IMU) ---
#define I2C_SDA_PIN   18
#define I2C_SCL_PIN   21
#define I2C_CLOCK_HZ  400000UL  // 400 kHz fast-mode

// --- Onboard RGB LED (WS2812 / NeoPixel on ESP32-S3-DevKitC-1) ---
#define LED_PIN       48

// --- Potentiometer (analog dial for menu navigation) ---
// Repurposed from SERVO2_PIN (GPIO 9) — ADC1 channel.
#define POT_PIN       9

// --- SPI Display (I2C-style labels: SDA=MOSI, SCL=SCLK) ---
#define DISPLAY_MOSI  37   // SDA on module
#define DISPLAY_SCLK  38   // SCL on module
#define DISPLAY_CS    35
#define DISPLAY_DC    36
#define DISPLAY_RES   39

// --- Push Buttons (INPUT_PULLUP, active LOW) ---
#define BUTTON1_PIN   41
#define BUTTON2_PIN   42
// BTN3/GPIO47 is not populated on the current hardware.

// --- Hall Effect Sensors ---
#define HALL1_PIN     1
#define HALL2_PIN     2

// --- Expansion Header GPIO ---
// These pins are broken out on the expansion header for future use.
// #define EXP_GPIO_37  37   // now used: DISPLAY_MOSI
// #define EXP_GPIO_38  38   // now used: DISPLAY_SCLK
// #define EXP_GPIO_39  39   // now used: DISPLAY_RES
// #define EXP_GPIO_40  40
// #define EXP_GPIO_43  43
// #define EXP_GPIO_44  44
// #define EXP_GPIO_48  48

// --- LEDC PWM (motor control) ---
#define MOTOR_PWM_FREQ      20000   // 20 kHz — above audible range
#define MOTOR_PWM_RESOLUTION    8   // 8-bit: 0–255
#define MOTOR1A_CHANNEL         0
#define MOTOR1B_CHANNEL         1
#define MOTOR2A_CHANNEL         2
#define MOTOR2B_CHANNEL         3

// --- Servo ---
#define SERVO_MIN_US    1000    // 0°
#define SERVO_MAX_US    2000    // 180°

// --- Ultrasonic ---
#define ULTRASONIC_TIMEOUT_US   30000UL // 30 ms → ~5 m max range
#define SOUND_SPEED_CM_PER_US   0.0343f // cm per µs (at ~20°C)

// --- Buttons ---
#define BUTTON_DEBOUNCE_MS  20

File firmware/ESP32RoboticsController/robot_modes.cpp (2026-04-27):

#include "robot_modes.h"
#include "autonomous_modes.h"
#include "display.h"
#include "buttons.h"
#include "led.h"
#include "pot.h"
#include "motors.h"
#include "ultrasonics.h"
#include "imu.h"
#include <XboxSeriesXControllerESP32_asukiaaa.hpp>

// =============================================================================
// Robot Modes â€” wires the autonomous_modes engine into the UI menu.
//
// Sensor mapping (4Ã— HC-SR04):
//   US1 = front   US2 = left   US3 = right   US4 = rear (unused by engine)
//
// Motor mapping:
//   MOTOR1 = left track    MOTOR2 = right track
// =============================================================================

// ---------------------------------------------------------------------------
// Layout constants (mirror ui.cpp conventions)
// ---------------------------------------------------------------------------
static constexpr int16_t RM_HDR_H     = 13;
static constexpr int16_t RM_HDR_BOT   = RM_HDR_H + 1;
static constexpr int16_t RM_FOOT_Y    = DISP_H - ROW_PX - 1;
static constexpr int16_t RM_CONTENT_H = RM_FOOT_Y - RM_HDR_BOT;

// ---------------------------------------------------------------------------
// Mode descriptor (use a different name to avoid clash with RobotMode enum)
// ---------------------------------------------------------------------------
struct RModeEntry {
    const char *label;   // short name shown in the list   (â‰¤16 chars)
    const char *desc;    // one-line description shown below the list
    void (*run)();       // called every loop() tick while mode is active
};

// ---------------------------------------------------------------------------
// Autonomous engine — singleton
// ---------------------------------------------------------------------------
static RobotModes _am;
static bool       _am_ready = false;

// ---------------------------------------------------------------------------
// Xbox BLE controller — singleton
// ---------------------------------------------------------------------------
static XboxSeriesXControllerESP32_asukiaaa::Core _xbox;
static bool _xbox_ready = false;

static void _xbox_ensure_ready() {
    if (!_xbox_ready) {
        _xbox.begin();
        _xbox_ready = true;
    }
}

static void _motor_cb(int left, int right) {
    motor_set(MotorId::MOTOR1, left);
    motor_set(MotorId::MOTOR2, right);
}

// Build a SensorInput from board peripherals (rate-limited by callers).
static SensorInput _read_sensors() {
    SensorInput s = {};

    // Ultrasonics: US1=front, US2=left, US3=right
    float us[4] = { 0, 0, 0, 0 };
    ultrasonics_read_all_cm(us);
    s.distFront = (us[0] > 0.0f) ? us[0] : 400.0f;
    s.distLeft  = (us[1] > 0.0f) ? us[1] : 400.0f;
    s.distRight = (us[2] > 0.0f) ? us[2] : 400.0f;
    s.wallAngle = 0.0f;

    // IMU â€” convert m/sÂ² â†’ g
    ImuData imu = {};
    if (imu_read(imu)) {
        s.accelX = imu.accel_x / 9.81f;
        s.accelY = imu.accel_y / 9.81f;
        s.accelZ = imu.accel_z / 9.81f;
        s.gyroX  = imu.gyro_x;
        s.gyroY  = imu.gyro_y;
        s.gyroZ  = imu.gyro_z;
    }

    s.rcConnected = false;
    return s;
}

static void _am_ensure_ready() {
    if (!_am_ready) {
        _am.setMotorCallback(_motor_cb);
        _am_ready = true;
    }
}

// Small live HUD drawn at top of content area (called every update cycle).
static void _draw_hud(const SensorInput &s) {
    int ml = 0, mr = 0;
    _am.getMotorSpeeds(ml, mr);

    char line1[22], line2[22];
    snprintf(line1, sizeof(line1), "L:%-4d R:%-4d", ml, mr);
    snprintf(line2, sizeof(line2), "F:%.0f L:%.0f R:%.0f",
             s.distFront, s.distLeft, s.distRight);

    display_fill_rect(0, RM_HDR_BOT,              DISP_W, ROW_PX + 1, C_BG);
    display_fill_rect(0, RM_HDR_BOT + ROW_PX + 2, DISP_W, ROW_PX + 1, C_BG);
    display_text(2, RM_HDR_BOT,              line1, C_CYAN,   C_BG, 1);
    display_text(2, RM_HDR_BOT + ROW_PX + 2, line2, C_YELLOW, C_BG, 1);
}

// Core tick shared by all modes â€” called every loop(), rate-limited internally.
static void _tick(RobotMode mode) {
    _am_ensure_ready();

    static unsigned long _last = 0;
    constexpr unsigned long RATE_MS = 50;   // ~20 Hz (each ultrasonic read ~10 ms)
    if (millis() - _last < RATE_MS) return;
    _last = millis();

    _am.setMode(mode);
    SensorInput s = _read_sensors();
    _am.update(s);
    _draw_hud(s);
}

// ---------------------------------------------------------------------------
// Per-mode tick wrappers
// ---------------------------------------------------------------------------
static void _run_rc() {
    _am_ensure_ready();
    _xbox_ensure_ready();

    // Let the library manage BLE scanning / reconnection every tick
    _xbox.onLoop();

    // Control update at ~50 Hz
    static unsigned long _last_rc = 0;
    constexpr unsigned long RC_RATE_MS = 20;
    if (millis() - _last_rc < RC_RATE_MS) return;
    _last_rc = millis();

    SensorInput s = {};
    if (_xbox.isConnected()) {
        // joyLVert: 0 = full up (forward), 0xffff = full down (backward)
        // joyRHori: 0 = full left,          0xffff = full right
        int throttle = (32767 - (int)_xbox.xboxNotif.joyLVert) / 64;  // -512..512
        int steering = ((int)_xbox.xboxNotif.joyRHori - 32767)  / 64; // -512..512
        s.rcThrottle  = throttle;
        s.rcSteering  = steering;
        s.rcConnected = true;
    } else {
        s.rcConnected = false;
    }

    _am.setMode(MODE_RC_CONTROL);
    _am.update(s);

    // HUD
    int ml = 0, mr = 0;
    _am.getMotorSpeeds(ml, mr);
    char line1[22], line2[22];
    snprintf(line1, sizeof(line1), "L:%-4d R:%-4d", ml, mr);
    if (_xbox.isConnected()) {
        snprintf(line2, sizeof(line2), "T:%-4d S:%-4d",
                 (int)s.rcThrottle, (int)s.rcSteering);
    } else {
        snprintf(line2, sizeof(line2), "Scanning BLE...");
    }
    display_fill_rect(0, RM_HDR_BOT,               DISP_W, ROW_PX + 1, C_BG);
    display_fill_rect(0, RM_HDR_BOT + ROW_PX + 2,  DISP_W, ROW_PX + 1, C_BG);
    display_text(2, RM_HDR_BOT,               line1, C_CYAN, C_BG, 1);
    display_text(2, RM_HDR_BOT + ROW_PX + 2,  line2,
                 _xbox.isConnected() ? C_YELLOW : C_ORANGE, C_BG, 1);
}
static void _run_uart()   { _tick(MODE_UART_CONTROL); }
static void _run_sok()    { _tick(MODE_SOK_CONTROL);  }
static void _run_auto()   { _tick(MODE_AUTONOMOUS);   }
static void _run_simple() { _tick(MODE_SIMPLE_AUTO);  }
static void _run_wall()   { _tick(MODE_WALL_FOLLOW);  }
static void _run_premap() { _tick(MODE_PREMAP_NAV);   }
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

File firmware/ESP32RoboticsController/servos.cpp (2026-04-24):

#include "servos.h"

static Servo _servo1;

static void _ensure_servo1() {
    if (!_servo1.attached()) {
        _servo1.setPeriodHertz(50);
        _servo1.attach(SERVO1_PIN, SERVO_MIN_US, SERVO_MAX_US);
    }
}

void servos_init() {
    // Servo 2 disabled — SERVO2_PIN (GPIO 9) repurposed for potentiometer.
    // Servo 1 attached on-demand via servo_set_angle / servo_set_us to avoid
    // LEDC channel conflicts with motors during boot.
}

void servo_set_angle(ServoId servo, int degrees) {
    if (servo != ServoId::SERVO1) return;  // servo2 repurposed
    degrees = constrain(degrees, 0, 180);
    _ensure_servo1();
    _servo1.write(degrees);
}

void servo_set_us(ServoId servo, int pulse_us) {
    if (servo != ServoId::SERVO1) return;  // servo2 repurposed
    pulse_us = constrain(pulse_us, SERVO_MIN_US, SERVO_MAX_US);
    _ensure_servo1();
    _servo1.writeMicroseconds(pulse_us);
}

void servo_detach(ServoId servo) {
    if (servo == ServoId::SERVO1 && _servo1.attached()) {
        _servo1.detach();
    }
}

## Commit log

2026-04-03 Create initial PCB project starter base with firmware and hardware structure
    Agent-Logs-Url: https://github.com/averyizatt/ESP32BasedRobiticsPCB/sessions/d9f3cad1-dcbc-4a22-a679-e6851b55c6f7
    [bom.csv]
2026-04-03 Add PCB images to README
    Agent-Logs-Url: https://github.com/averyizatt/ESP32BasedRobiticsPCB/sessions/4e5fb9b7-d99e-4026-89df-6d83c5fe2d7e
2026-04-03 docs: significantly enhance README with badges, ToC, architecture diagram, and deeper technical detail
    Agent-Logs-Url: https://github.com/averyizatt/ESP32BasedRobiticsPCB/sessions/25968c5d-c666-468f-8afb-e7f4a778fa04
2026-04-03 Kicad project files for the Tank project. These files include the PCB layout, schematic, and related resources. The project is organized in a way that allows for easy navigation and modification of t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
    [Tank.kicad_pcb, Tank.kicad_sch, Tank.step]
2026-04-24 ESP Board Updates
